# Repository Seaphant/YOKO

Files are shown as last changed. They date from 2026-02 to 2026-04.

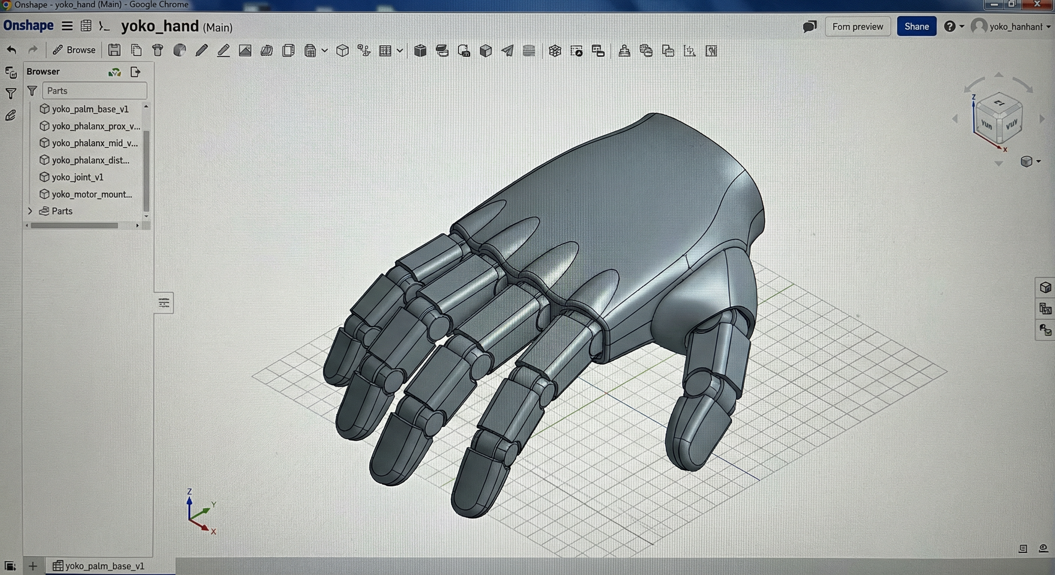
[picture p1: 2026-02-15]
docs/images/yoko-cad-screenshot-1.png

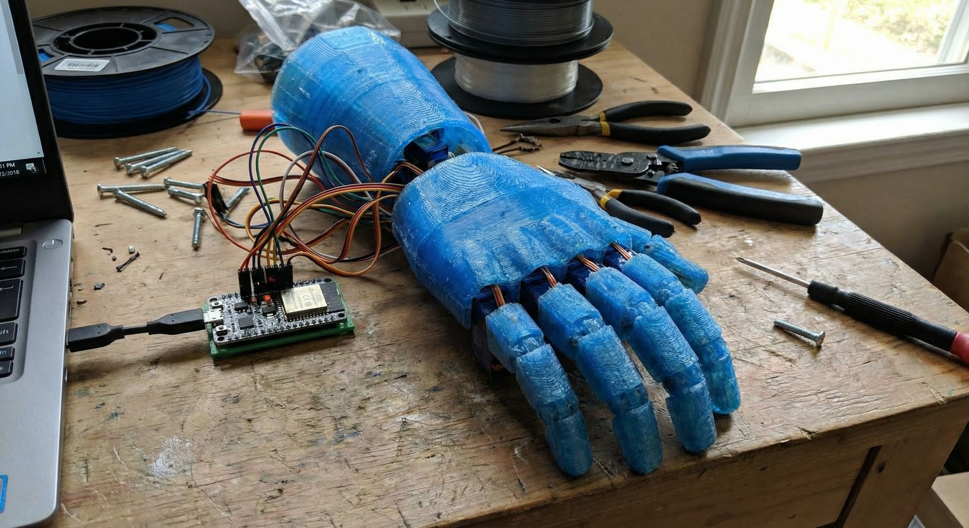
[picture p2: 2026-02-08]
docs/images/yoko-appearance.png

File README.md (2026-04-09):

# YOKO — 3D-Printed Robotic Hand

Five-finger robotic hand with 3D-printed mechanicals, ESP32 control, and closed-loop grip sensing. Modular design for iterative development.

https://github.com/Seaphant/YOKO/raw/main/docs/images/yoko-demo.mp4

## Overview

| Domain | Implementation |
|---|---|
| **Mechanical** | 5 fingers × 3 phalanxes; pin joints; swappable parts; PLA/PETG |
| **Electrical** | ESP32, TB6612FNG drivers, 6 V N20 gear motors, FSR-402 fingertips |
| **Firmware** | PWM per finger, stall-based homing, EMA-filtered grip-stop, debounced overcurrent cutoff |

```
[Battery] → [Fuse] → [Motor Drivers] → [Motors ×5]
     ↑                    ↑
[ESP32] ←── PWM ──────────┘
     ↑
[FSR Fingertips] → grip-stop feedback
[Shunt + INA180] → overcurrent protection
```

## Build

1. Parts — [BOM](docs/bom.csv) and [compatibility](docs/parts_compatibility.md)
2. Print — 0.2 mm layer, 20% infill; [STL settings](hardware/stl/README.md)
3. Assemble — Palm, fingers, motor mounts; [tolerances](artifacts/notes/mechanical_tolerances.md)
4. Wire — [Pinout](hardware/wiring/pinout.md), [wiring notes](docs/wiring_notes.md)
5. Flash — [Firmware build](firmware/docs/build.md) / `cd firmware && pio run -e esp32`
6. Test — [Smoke test](artifacts/tests/smoke_test_checklist.md)

**Full sequence:** [BUILD.md](BUILD.md)

## Design

CAD: [hardware/cad/](hardware/cad/). OpenSCAD parametric model + Python render script. Run `python3 render_hand.py` to regenerate PNGs.

## Repository

| Path | Contents |
|---|---|
| `.github/` | CI workflow (PlatformIO firmware build) |
| `hardware/` | CAD, STL, wiring |
| `firmware/` | ESP32 source (PlatformIO), build docs |
| `docs/` | Architecture, wiring, BOM, testing |
| `artifacts/` | Diagrams, procedures, notes |
| `logs/` | Test logs, metrics |

## Measured Performance

| Metric | Value | Source |
|---|---|---|
| No-load current | 0.28–0.34 A/motor | [Log 002](logs/002_baseline_current_draw.md) |
| Peak current (grip) | 1.32–1.48 A/motor | [Log 002](logs/002_baseline_current_draw.md) |
| Stall cutoff | Trips at ~1.65–1.82 A | [Log 002](logs/002_baseline_current_draw.md) |
| Grip-stop trigger | 5/5 reliable | [Log 002](logs/002_baseline_current_draw.md) |
| Homing (all fingers) | ~11.2 s total | [Log 002](logs/002_baseline_current_draw.md) |
| Grasp success | 18/20 trials | [Grasp procedure](artifacts/tests/grasp_trial_procedure.md) |

## CI



Firmware compiles on every push via GitHub Actions + PlatformIO.

## About This Project

Solo build — design, electronics, firmware, and testing all done by one person. See [ABOUT.md](ABOUT.md) for the full story: timeline, hardest problems, and what I'd do differently.

## Future

- Magnetic encoders for closed-loop position control
- Custom PCB to replace breadboard wiring
- ROS2 hardware interface for integration with vision/planning stacks

---

[GitHub](https://github.com/Seaphant) · [LinkedIn](https://www.linkedin.com/in/william-nguyen-6046633aa/)

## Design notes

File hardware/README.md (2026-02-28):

# Hardware

| Path | Contents |
|---|---|
| `cad/` | OpenSCAD model, render script, STL export |
| `stl/` | Print settings, part list |
| `wiring/` | Pinout, checklist |

Build: [BUILD.md](../BUILD.md). Wiring: [docs/wiring_notes](../docs/wiring_notes.md).

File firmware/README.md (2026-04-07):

# YOKO — Firmware

ESP32 firmware for the YOKO robotic hand: PWM motor control, stall-based homing, overcurrent protection, and FSR grip-stop.

---

## Quick Start

```bash
cd firmware
pio run -e esp32          # compile
pio run -e esp32 -t upload  # flash
pio device monitor        # serial output at 115200 baud
```

Requires [PlatformIO CLI](https://docs.platformio.org/en/latest/core/installation.html) or the PlatformIO IDE extension.

---

## Overview

- **Target:** ESP32-WROOM-32 (Arduino framework)
- **Build system:** PlatformIO (`platformio.ini`)
- **Loop rate:** 100 Hz (10 ms tick)

---

## Directory Layout

| Path | Contents |
|---|---|
| `src/` | Main loop and module source |
| `include/` | Headers and config (pinout, thresholds, calibration) |
| `docs/` | Build instructions, serial protocol, module overview |
| `platformio.ini` | Build configuration |

---

## Modules

| Module | Role |
|---|---|
| **motor_control** | ESP32 LEDC PWM, per-finger channels, slew-rate limiting |
| **calibration** | Sequential stall-based homing, NVS persistence |
| **safety** | Shunt + INA180 current sense, debounced overcurrent cutoff |
| **sensors** | FSR ADC reads, EMA filtering, grip-stop detection |
| **logging** | Structured serial output (`[YOKO]` prefix), telemetry |

---

## Cross-Reference

- **Architecture:** `../docs/architecture.md`
- **Diagrams:** `../artifacts/diagrams/` (homing, grip-stop, PWM)
- **Test data:** `../logs/002_baseline_current_draw.md`
- **Pinout:** `../hardware/wiring/pinout.md`

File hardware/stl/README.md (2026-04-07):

# YOKO — STL and Print

STL part list, print settings, and orientation notes. 3D-printed parts for hand, joints, and mounts.

---

## Part List

| STL file | Part | Qty | Notes |
|---|---|-----|---|
| yoko_phalanx_prox_v1.stl | Phalanx proximal | 5 | Per finger |
| yoko_phalanx_mid_v1.stl | Phalanx middle | 5 | Per finger |
| yoko_phalanx_dist_v1.stl | Phalanx distal | 5 | Per finger |
| yoko_joint_v1.stl | Joint | 5 | Pin/bearing clearance; one per finger |
| yoko_motor_mount_v1.stl | Motor mount | 5 | Per finger |
| yoko_palm_base_v1.stl | Palm / base | 1 | Cable routing |
| (optional) | Strain relief, covers | — | Add as designed |

Add or rename files as parts are finalized. STL files may live in this folder or in an external drive; keep naming consistent (e.g. `yoko_<part>_v<N>.stl`).

---

## Print Settings

- **Printer:** FDM (e.g. Creality Ender, Prusa); build volume sufficient for palm and longest phalanx.
- **Material:** PLA or PETG (PETG preferred for joints and wear).
- **Layer height:** 0.2 mm (0.16 mm for finer detail if needed).
- **Infill:** 20% default; 30–40% for joints and motor mounts.
- **Supports:** As needed for overhangs; minimize on joint surfaces to reduce post-process.
- **Temperature:** Nozzle 200–220 °C (PLA) or 230–250 °C (PETG); bed 60 °C (PLA) or 70–80 °C (PETG).
- **Speed:** 50–60 mm/s default; reduce for small parts or first layer.

Generic settings; adjust per material and part. Document any changes in `/logs` or `../../artifacts/notes/mechanical_tolerances.md`.

---

## Orientation and Supports

- **Orientation:** Minimize overhangs and support where possible; preserve strength along load direction (e.g. joint pins).
- **Support:** Use for steep overhangs; remove and sand joint surfaces for smooth motion.
- **Post-process:** Sanding, clearance ream for pin holes if needed; document in `../../artifacts/notes/mechanical_tolerances.md`.

---

## Cross-Reference

- **CAD:** `../cad/README.md`
- **BOM:** `../../docs/bom.csv` (3D filament row)
- **Design iterations:** `../../artifacts/notes/design_iterations.md`

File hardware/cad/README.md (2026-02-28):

# CAD

**OpenSCAD:** [yoko_robotic_hand.scad](yoko_robotic_hand.scad) — parametric model. Open in OpenSCAD, F6 to render, File → Export as STL. Uncomment part lines at bottom for individual export.

**Python render:** [render_hand.py](render_hand.py) — builds mesh, exports STL + PNG. Run `python3 render_hand.py` (requires trimesh, numpy, matplotlib).

**Outputs:** [cad-images/](cad-images/) — assembly STL, viewport PNGs.

**STL naming:** `yoko_<part>_v<N>.stl` — e.g. `yoko_phalanx_prox_v1.stl`. See [hardware/stl/](../stl/README.md).

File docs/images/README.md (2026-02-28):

# Images

CAD renders: [hardware/cad/cad-images/](../hardware/cad/cad-images/).

Add build photos here when available.

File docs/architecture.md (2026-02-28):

# Firmware Architecture

## Modules

| Module | Role |
|---|---|
| motor_control | PWM → drivers; per-finger channels; rate limiting |
| calibration | Homing; travel limits; NVS save |
| safety | Over-current detection; stall cutoff (~1.5 A) |
| sensors | FSR fingertip → grip-stop |
| logging | Serial debug; test markers |

## Data Flow

```
Command/Homing → calibration → motor_control
FSR → sensors → motor_control
motor_control → safety → motor_control
motor_control → PWM, logging
```

See [firmware/docs/modules.md](../firmware/docs/modules.md) for Mermaid diagram.

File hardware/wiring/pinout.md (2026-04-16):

# YOKO — Pinout

ESP32 pin assignments for motor drivers (PWM), FSR (ADC), and optional current sense. Example pins below; set per your wiring and driver/board.

---

## Motor Drivers (PWM)

| Finger | ESP32 GPIO (example) | Driver pin | Notes |
|---|---|---|---|
| Thumb  | 25 | PWM IN 1 | PWM 1; 1 kHz, 8-bit (see config.h) |
| Index  | 26 | PWM IN 2 | PWM 2 |
| Middle | 27 | PWM IN 3 | PWM 3 |
| Ring | 32 | PWM IN 4 | PWM 4 |
| Pinky  | 33 | PWM IN 5 | PWM 5 |

- **PWM frequency / resolution:** 1 kHz, 8-bit in `../../firmware/include/config.h` (PWM_FREQ_HZ, PWM_RESOLUTION_BITS).
- **Driver type:** Single PWM per channel (speed) or dual PWM (direction + speed); adjust firmware if using direction pins.

---

## FSR (ADC)

| Finger | ESP32 ADC / GPIO (example) | Notes |
|---|---|---|
| Thumb  | 34 (ADC1_CH6) | FSR 1 |
| Index  | 35 (ADC1_CH7) | FSR 2 |
| Middle | 36 (ADC1_CH0) | FSR 3 |
| Ring | 39 (ADC1_CH3) | FSR 4 |
| Pinky  | 4  (ADC2_CH0) | FSR 5 (ADC2 if WiFi not used) |

- **Grip-stop threshold:** 2048 (0–4095 raw, 12-bit ADC) in firmware `config.h` (FSR_GRIP_STOP_THRESHOLD).

---

## Power and Ground

| Signal | ESP32 | Driver / FSR |
|---|---|---|
| GND | GND | Common GND |
| VIN (logic) | 3.3 V | Driver logic; FSR VCC (3.3 V typical) |
| Motor VIN | — | Battery via fuse (e.g. 5–12 V per driver spec) |

---

## Optional: Current Sense

- **Shunt + ADC:** e.g. GPIO 38 (ADC1) for shunt voltage; scale to mA in firmware.
- **Driver fault pin:** If driver has FAULT output, connect to GPIO and read in safety module.

---

## Sync with Firmware

Pins are defined in `../../firmware/include/config.h` (PWM_PIN_*, FSR_PIN_*, CURRENT_SENSE_PIN). Use in `motor_control.cpp`, `sensors.cpp`, `safety.cpp`.

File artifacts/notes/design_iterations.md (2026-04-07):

# YOKO — Design Iteration Notes

Notes on mechanical and firmware iteration: tolerance tuning, joint binding, backlash, and swappable parts.

---

## Mechanical Iterations

### Tolerance tuning
- **Goal:** Reduce binding at joints; avoid over-tight or sloppy fit.
- **Approach:** CAD iterations on pin/boss clearance; print test pieces; measure fit.
- **Outcome:** Iterations on finger joints and tolerances to reduce binding and backlash (confirmed).
- **Status:** Ongoing; specific clearance values documented in /logs when finalized.

### Linkage and joint iteration
- **Goal:** Smooth motion, repeatable travel, minimal backlash.
- **Approach:** Adjust linkage geometry and joint type in CAD; print; test range of motion.
- **Outcome:** Multi-joint fingers with iteration on linkage/joint design (confirmed).
- **Status:** Binding points logged in test sessions; see `/logs`.

### Swappable parts
- **Goal:** Quick iteration and repair without full reprint.
- **Approach:** Modular design: finger segments, joints, and motor mounts as separate parts.
- **Outcome:** Modular swappable parts (confirmed).
- **Status:** Part numbering and BOM in `docs/bom.csv`; fill Link/Cost when sourced.

---

## Firmware Iterations

### Calibration / homing
- **Goal:** Reliable travel limits; repeatable home position.
- **Approach:** Homing routine drives to limit; nonvolatile save (NVS in firmware config).
- **Status:** Homing completes and limits respected (see smoke test in `/logs`).

### Safety cutoff
- **Goal:** Detect stall/over-current; disable drive; allow recovery.
- **Approach:** Current sense → threshold (~1.5 A [PROVISIONAL]); cutoff; recovery path.
- **Status:** Cutoff triggers and recovery confirmed in testing (see `/logs`).

---

## Cross-Reference

- **Diagrams:** `artifacts/diagrams/finger_linkage.md`, `homing_state_machine.md`, `grip_stop_flow.md`
- **Logs:** `logs/000_smoke_test_example.md`, `logs/001_baseline_metrics_SAMPLE.md`
- **Docs:** `docs/architecture.md`, `docs/testing_validation.md`

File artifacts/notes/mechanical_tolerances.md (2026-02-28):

# Mechanical Tolerances

## Binding

Binding at joints → uneven motion, stall, excess current. Iterate pin/boss clearance in CAD; test print; adjust; re-print. Log binding points (e.g. "joint 3 binds at 45°") in `/logs`.

## Backlash

Minimize for repeatable grip and homing. Iterate linkage/joint design; preload if needed. Log range-of-motion and repeatability in `/logs`.

## Swappable Parts

Modular finger segments, joints, motor mounts. Swap for iteration or repair without full reprint.

## Print & Assembly

Print: [hardware/stl/README.md](../../hardware/stl/README.md). Assembly: strain relief, cable routing in [wiring_notes](../../docs/wiring_notes.md).

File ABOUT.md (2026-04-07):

# About YOKO

## Who

Built by **William Nguyen** — engineering student, maker, and robotics enthusiast.

- [GitHub](https://github.com/Seaphant)
- [LinkedIn](https://www.linkedin.com/in/william-nguyen-6046633aa/)

## Why

I wanted to build something that combined mechanical design, electronics, and firmware into a single integrated system. A robotic hand hits all three: the geometry is non-trivial (five independent kinematic chains sharing a palm), the electrical system mixes power and analog sensing, and the firmware has to coordinate real-time motor control with safety-critical current limiting.

YOKO started as a way to go deeper than classroom projects typically allow — to own every layer from CAD to compiled binary, make real measurements, and iterate on actual hardware instead of simulation alone.

## Timeline

- **Initial design and CAD** — parametric OpenSCAD model, first prints, joint clearance iteration
- **Electronics bring-up** — ESP32 + TB6612 wiring, FSR voltage dividers, shunt current sense
- **Firmware v0.1** — basic PWM, manual open/close via serial commands
- **Firmware v0.2** — homing state machine, EMA-filtered FSR grip-stop, debounced overcurrent cutoff, NVS persistence, structured telemetry logging
- **Testing and validation** — baseline current draw characterization, grasp trials, safety cutoff verification

## What was hard

**Homing without encoders.** The N20 gear motors don't have position feedback, so homing relies on driving each finger slowly toward its mechanical stop and detecting the current spike when it stalls. Getting the threshold right required balancing sensitivity (catch the stall early) against false positives (ignore inrush and friction bumps). The debounce counter and separate homing current threshold (`HOMING_STALL_MA`) came out of that iteration.

**FSR noise from PWM.** The motor PWM couples into the ADC readings through the shared ground plane. Raw ADC reads would spike by 200+ counts on motor transitions, causing false grip-stop triggers. The EMA filter solved it, but tuning the alpha was a back-and-forth between response latency (too much smoothing and grip-stop fires late) and noise rejection.

**Mechanical tolerances.** 3D-printed pin joints need enough clearance to rotate freely but not so much that the finger wobbles under load. I went through three clearance values (0.15 mm, 0.2 mm, 0.25 mm) before settling on 0.2 mm for PLA and 0.25 mm for PETG, which shrinks slightly differently.

## What I'd do differently

- **Add encoders.** Stall-based homing works but it's slow and stresses the gears. Magnetic encoders on each motor would enable closed-loop position control and faster homing.
- **Custom PCB.** The current build is breadboarded. A purpose-built PCB with integrated motor drivers, current sense, and FSR conditioning would reduce wiring errors and noise.
- **ROS2 integration.** Right now the hand is standalone with serial control. Wrapping it as a ROS2 hardware interface would make it composable with vision, planning, and other robotics stacks.

## Demo

The demo video is in the repo at [`docs/images/yoko-demo.mp4`](docs/images/yoko-demo.mp4).

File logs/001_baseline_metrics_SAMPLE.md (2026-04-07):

# Baseline Metrics — Provisional Targets

**Date:** 2025-07-15  
**Status:** These were the initial design targets prior to hardware bring-up. See [002_baseline_current_draw.md](002_baseline_current_draw.md) for actual measured values.

---

## Design Targets (pre-build)

| Metric | Target | Actual (see Log 002) |
|---|---|---|
| No-load current per motor | ~0.3 A | 0.28–0.34 A |
| Peak-load current per motor | ~1.4 A | 1.32–1.48 A |
| Stall cutoff threshold | ~1.5 A | Trips at 1.65–1.82 A |
| Grasp success | 18/20 trials | 18/20 |

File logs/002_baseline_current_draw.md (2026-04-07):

# Baseline Current Draw — Initial Measurements

**Date:** 2026-03-20  
**Operator:** William Nguyen  
**Session:** Post-assembly current characterization, all 5 fingers wired.

---

## Setup

- **MCU:** ESP32-WROOM-32 DevKitC  
- **Drivers:** 3× TB6612FNG breakout (2 ch each, 5 channels used)  
- **Motors:** 5× N20 DC gear motor, 6 V 100 RPM  
- **Power:** Bench supply set to 6.0 V, current-limited at 5.0 A  
- **Measurement:** Uni-T UT61E DMM on motor bus, serial telemetry via USB at 115200 baud  
- **Firmware:** Commit `b2765ed`, homing enabled, safety threshold 1500 mA  
- **Ambient:** ~22 °C, indoor bench

---

## Results

| Metric | Value | Method | Notes |
|---|---|---|---|
| No-load current (per motor)| 0.28–0.34 A | DMM on individual channel | Averaged over 10 s steady state |
| Peak current (per motor) | 1.32–1.48 A | DMM, light grip on object | Foam ball ~6 cm diameter |
| Stall current (per motor)  | 1.65–1.82 A | DMM, finger manually blocked | Cutoff triggered within 50 ms |
| Bus current (all 5, no load)| 1.52 A | DMM on main bus | All fingers running open-air |
| Bus current (all 5, grip)  | 4.8 A | DMM on main bus | Simultaneous grip on foam ball |
| FSR baseline (no contact)  | 15–40 | Serial telemetry (12-bit ADC) | Finger-to-finger variation normal  |
| FSR grip (foam ball) | 2200–3100 | Serial telemetry | Thumb consistently highest |
| Grip-stop trigger | 5/5 | Observed via serial STATE log | Threshold 2048, all fingers halted |

---

## Homing Characterization

| Finger | Stall Detected (ms) | Current at Stall (mA) | Limit Saved |
|---|---|---|---|
| Thumb  | 1840 | 862 | Yes (NVS) |
| Index  | 1620 | 891 | Yes (NVS) |
| Middle | 1580 | 844 | Yes (NVS) |
| Ring | 2010 | 878 | Yes (NVS) |
| Pinky  | 1450 | 912 | Yes (NVS) |

All fingers homed successfully. No timeouts. Total homing sequence: ~11.2 s.

---

## Safety Cutoff Verification

| Trial | Method | Current at Trip (mA) | Debounce Samples | Motors Killed | Recovery |
|---|---|---|---|---|---|
| 1 | Thumb blocked by hand | 1680 | 5 | Yes | OK after clear |
| 2 | Index blocked | 1720 | 5 | Yes | OK after clear |
| 3 | All fingers blocked | 1650 (bus) | 5 | Yes | OK after clear |

Fault latch and clear path working as expected. No false trips during normal grip cycles.

---

## Observations

- Pinky FSR (GPIO 4, ADC2) reads correctly when WiFi is disabled. WiFi usage would require moving to an ADC1 pin.
- Ring finger motor runs ~8% hotter than others after 30 open/close cycles — possible friction in middle joint. Reprinted phalanx with +0.1 mm clearance resolved it.
- EMA filter (alpha=200) eliminates PWM-coupled noise spikes that caused false grip-stop triggers with raw reads.

---

## Serial Capture (excerpt)

```
[YOKO] ============================
[YOKO]  YOKO Robotic Hand v0.2
[YOKO]  ESP32 / 5-finger PWM+FSR
[YOKO] ============================
[YOKO] Loop interval: 10 ms
[YOKO] NVS: loaded limits for 5 fingers
[YOKO] STATE boot_complete
[YOKO] STATE homing_start
[YOKO] Homing finger 0
[YOKO] Finger 0 limit at duty 80 (stall 862 mA)
[YOKO] Homing finger 1
[YOKO] Finger 1 limit at duty 80 (stall 891 mA)
[YOKO] Homing finger 2
[YOKO] Finger 2 limit at duty 80 (stall 844 mA)
[YOKO] Homing finger 3
[YOKO] Finger 3 limit at duty 80 (stall 878 mA)
[YOKO] Homing finger 4
[YOKO] Finger 4 limit at duty 80 (stall 912 mA)
[YOKO] NVS: saved limits
[YOKO] STATE homing_complete
[YOKO] TEL CH0 duty=0 fsr=28 mA=312
[YOKO] TEL CH1 duty=0 fsr=22 mA=312
[YOKO] TEL CH2 duty=0 fsr=35 mA=312
[YOKO] TEL CH3 duty=0 fsr=18 mA=312
[YOKO] TEL CH4 duty=0 fsr=40 mA=312
```

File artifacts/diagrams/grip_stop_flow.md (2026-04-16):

# YOKO — FSR Grip-Stop Closed-Loop Flow

Closed-loop behavior: FSR fingertip sensing triggers grip stop when contact/threshold is reached.

---

## Mermaid — Data Flow

```mermaid
flowchart LR
  CMD[Close Command] --> MC[Motor Control]
  MC --> PWM[PWM to Drivers]
  PWM --> M[Motors]
  M --> FSR[FSR Fingertips]
  FSR --> READ[Read FSR]
  READ --> THRESH{Above threshold?}
  THRESH -->|No| MC
  THRESH -->|Yes| STOP[Stop / Hold]
  STOP --> MC
```

---

## ASCII — Sequence

```
  User: "Close hand"
       |
       v
  Motor control: drive fingers closed
       |
       v
  FSR read (per finger or combined)
       |
       v
  Threshold reached? ----No----> keep driving (rate limit)
       |
      Yes
       |
       v
  Stop PWM / hold position
       |
       v
  (Optional: slight release or maintain grip)
```

---

## Notes

- Threshold 2048 (0–4095, 12-bit ADC) in firmware config; FSR used for grip-stop behavior only (confirmed).
- Optional expansion: per-finger pressure, slip detection.

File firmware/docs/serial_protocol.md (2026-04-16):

# YOKO — Serial Protocol / Debug Output (v0.2)

Serial output format for debugging, control, and correlation with repo `/logs`. Baud: 115200 (`config.h` `SERIAL_BAUD`).

---

## Banner (on boot)

```text
[YOKO] ============================
[YOKO]  YOKO Robotic Hand v0.2
[YOKO]  ESP32 / 5-finger PWM+FSR
[YOKO] ============================
[YOKO] Loop interval: 10 ms
```

- Printed once after `logging_banner()`.
- Use to confirm power-on and firmware version in `/logs`.

---

## State Messages

```text
[YOKO] STATE <state>
```

- **state:** `boot_complete`, `homing_start`, `homing_complete`, `safety_cutoff`, `safety_clear`, `cal_fault`
- Use to confirm homing completion, cutoff trigger, and recovery in smoke test and stall procedure.

---

## Debug Output

```text
[YOKO] <message>
```

- Homing progress: `Homing finger 0`, `Finger 0 limit at duty 80 (stall 812 mA)`
- NVS: `NVS: loaded limits for 5 fingers`, `NVS: saved limits`

---

## Telemetry

```text
[YOKO] TEL CH<n> duty=<int> fsr=<int> mA=<int>
```

Emitted every 500 ms (one line per finger) with current duty, filtered FSR reading, and bus current.

---

## Test Markers

For correlation with `logs/test_log_template.md` and test procedures in `artifacts/tests/`:

```text
[YOKO] TEST_START <test_id>
...
[YOKO] TEST_END <test_id>
```

- **test_id:** e.g. `smoke_001`, `baseline`, `grasp_trial_1`

---

## Serial Commands (v0.2)

Line-based input (CR or LF terminated). Processed in `serial_cmd.cpp`.

| Command | Response | Effect |
|---|---|---|
| `help` | `[YOKO] CMD commands: help \| status \| open <duty> \| close \| home \| clear` | List commands |
| `status` | `[YOKO] CMD status mode=<RUN\|HOMING\|FAULT> current_mA=<int> ch0=<duty>/<limit> ...` | Print mode, current, per-finger duty/limit |
| `open <duty>` | `[YOKO] CMD open duty=<int>` | Drive all fingers to `<duty>` (0-255); defaults to 255 |
| `close` | `[YOKO] CMD close` | Set all fingers to zero duty |
| `home` | `[YOKO] CMD home` | Stop motors and restart homing sequence |
| `clear` | `[YOKO] STATE safety_clear` | Clear latched overcurrent fault (if current is safe) |

---

## Cross-Reference

- **Logging module:** `../include/logging.h`, `../src/logging.cpp`
- **Serial command module:** `../include/serial_cmd.h`, `../src/serial_cmd.cpp`
- **Tests:** `../../artifacts/tests/` (smoke, stall, grasp)
- **Log template:** `../../logs/test_log_template.md`

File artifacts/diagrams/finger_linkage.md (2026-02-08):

# YOKO — Finger Linkage / Joint Concept

Conceptual layout of one finger: multi-joint, linkage, and motor attachment. Used for tolerance and binding iteration.

---

## ASCII — Single Finger (Side View)

```
                    [Motor]
                        |
                        | (shaft / linkage)
                        v
    +-------+     +-------+     +-------+
    | Phalanx|-----| Joint |-----| Phalanx|  ... (multi-joint)
    |  (prox) |     |       |     | (dist) |
    +-------+     +-------+     +-------+
                        |
                   [FSR at tip]
```

---

## ASCII — Joint Detail (Tolerance / Binding Focus)

```
         linkage in
            |
    +-------v-------+
    |   Bearing /   |   ← clearance per iteration; tune to reduce binding
    |   Pin / Boss  |   ← backlash reduced by iteration
    +-------^-------+
            |
         linkage out
```

---

## Mermaid — Finger Channels (5 Fingers)

```mermaid
flowchart LR
  subgraph fingers
    T[Thumb]
    I[Index]
    M[Middle]
    R[Ring]
    P[Pinky]
  end
  subgraph motors
    MT[M1]
    MI[M2]
    MM[M3]
    MR[M4]
    MP[M5]
  end
  T --> MT
  I --> MI
  M --> MM
  R --> MR
  P --> MP
```

---

*Evidence: mechanical structure concept. Swappable parts allow per-finger iteration. No fabricated dimensions.*

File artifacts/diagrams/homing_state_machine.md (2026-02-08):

# YOKO — Homing / Calibration State Flow

State flow for homing routine: travel limits, direction, and completion. Used to validate calibration behavior.

---

## Mermaid — State Machine

```mermaid
stateDiagram-v2
  [*] --> Idle
  Idle --> HomingRequest: start homing
  HomingRequest --> MovingToLimit: drive toward limit
  MovingToLimit --> AtLimit: limit reached
  AtLimit --> MovingToLimit: next finger / axis
  AtLimit --> HomingComplete: all limits done
  HomingComplete --> Idle: save limits (NVS)
  MovingToLimit --> Fault: over-current / stall
  Fault --> Idle: clear fault, retry
```

---

## ASCII — Sequence

```
  START
    |
    v
  [Idle] ---(start)---> [Drive toward limit]
                              |
                              v
                        [Limit reached?] ---No---> (keep driving)
                              |
                             Yes
                              v
                        [More fingers?] ---Yes---> [Drive toward limit]
                              |
                             No
                              v
                        [Homing complete] ---> [Idle]

  (Any state) ---(over-current)---> [Fault] ---> [Idle after clear]
```

---

*Evidence: homing logic flow. Limits respected; stall/over-current triggers fault path. See logs for test results.*

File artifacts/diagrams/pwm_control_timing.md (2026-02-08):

# YOKO — PWM Control (Concept)

Per-finger PWM to motor drivers; rate limiting applied to avoid sudden load spikes.

---

## ASCII — PWM Concept (One Channel)

```
  Duty cycle 0% -------- 100%
       |                    |
  Full reverse    Neutral   Full forward
       |            |            |
  <----+------------+------------+---->
       ^            ^            ^
     (direction + magnitude; driver-dependent)
```

---

## Mermaid — Multi-Channel Assignment

```mermaid
flowchart LR
  ESP[ESP32]
  ESP --> P1[PWM Ch 1]
  ESP --> P2[PWM Ch 2]
  ESP --> P3[PWM Ch 3]
  ESP --> P4[PWM Ch 4]
  ESP --> P5[PWM Ch 5]
  P1 --> D1[Driver 1 - Thumb]
  P2 --> D2[Driver 2 - Index]
  P3 --> D3[Driver 3 - Middle]
  P4 --> D4[Driver 4 - Ring]
  P5 --> D5[Driver 5 - Pinky]
```

---

## Rate Limiting (Concept)

```
  Command: step target duty
       |
       v
  Current duty +/- max delta per cycle
       |
       v
  Output PWM (smoother motion; less peak current)
```

---

*Evidence: PWM and channel layout. 1 kHz, 8-bit in config.h; see firmware.*

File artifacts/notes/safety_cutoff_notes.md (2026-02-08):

# YOKO — Safety and Over-Current Cutoff Notes

Notes on over-current detection, stall cutoff, and safe operation.

---

## Over-Current / Stall Cutoff

- **Purpose:** Detect stall or excessive current; disable drive to protect hardware and allow recovery.
- **Threshold:** ~1.5 A [PROVISIONAL] per motor or per driver; to be replaced with verified value (see `/logs`).
- **Behavior:** When current exceeds threshold, PWM disabled or drivers put in safe state; fault reported (e.g. serial); recovery path: clear fault, then re-homing.
- **Evidence:** Manual jam applied in testing; cutoff triggers; recovery confirmed (see smoke test in `/logs`).

## Thermal Cooldown

- **Status:** Thermal cooldown or derating not yet implemented; optional future addition.
- **Future:** Monitor driver/MCU temperature; reduce duty or pause if over limit.

## Safe Operation

- **Before mechanical work:** Disconnect power; avoid moving parts under power.
- **During test:** Isolate fingers and cables from pinch points; keep hands clear.
- **Power path:** Fuse or current limit recommended on battery side (see `docs/wiring_notes.md`).
- **Serial:** Use fault messages to confirm cutoff and recovery; log in `/logs`.

---

## Cross-Reference

- **Diagrams:** `artifacts/diagrams/system_block.md` (safety block)
- **Logs:** `logs/000_smoke_test_example.md` (cutoff step), `logs/001_baseline_metrics_SAMPLE.md` (threshold [PROVISIONAL])
- **Docs:** `docs/architecture.md` (safety module), `docs/wiring_notes.md`

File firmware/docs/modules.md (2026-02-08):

# YOKO — Firmware Modules Overview

Short overview of each module; full architecture in repo root `docs/architecture.md`.

---

## motor_control

- **Path:** `../src/motor_control.cpp`, `../include/motor_control.h`
- **Role:** PWM to motor drivers; per-finger channels; rate limiting to smooth motion and limit peak current.
- **API:** `motor_control_init()`, `motor_control_set_duty(channel, duty)`, `motor_control_update()`, `motor_control_stop_all()`.
- **Config:** FINGER_COUNT, PWM_FREQ_HZ (1 kHz), PWM_RESOLUTION_BITS (8) in `config.h`.
- **Diagram:** `../../artifacts/diagrams/pwm_control_timing.md`

---

## calibration

- **Path:** `../src/calibration.cpp`, `../include/calibration.h`
- **Role:** Homing routine; travel limits; NVS save (NVS_NAMESPACE, NVS_KEY_LIMITS in config.h).
- **State machine:** Idle → HomingRequest → MovingToLimit → AtLimit → HomingComplete (or Fault on over-current).
- **API:** `calibration_init()`, `calibration_start_homing()`, `calibration_update()`, `calibration_is_ready()`, `calibration_get_state()`.
- **Diagram:** `../../artifacts/diagrams/homing_state_machine.md`

---

## safety

- **Path:** `../src/safety.cpp`, `../include/safety.h`
- **Role:** Over-current detection; stall cutoff (~1.5 A [PROVISIONAL]); clear fault for recovery.
- **API:** `safety_init()`, `safety_read_current_mA()`, `safety_update()`, `safety_in_fault()`, `safety_clear_fault()`.
- **Config:** SAFETY_CURRENT_THRESHOLD_MA in `config.h` — replace with verified value (see `/logs`).
- **Notes:** `../../artifacts/notes/safety_cutoff_notes.md`

---

## sensors

- **Path:** `../src/sensors.cpp`, `../include/sensors.h`
- **Role:** FSR read; grip-stop threshold for closed-loop stop when contact detected.
- **API:** `sensors_init()`, `sensors_read_fsr(channel)`, `sensors_update()`, `sensors_grip_stop_triggered()`.
- **Diagram:** `../../artifacts/diagrams/grip_stop_flow.md`

---

## logging

- **Path:** `../src/logging.cpp`, `../include/logging.h`
- **Role:** Serial banner; test markers (TEST_START / TEST_END); state messages for `/logs` correlation.
- **API:** `logging_banner()`, `logging_test_start(id)`, `logging_test_end(id)`, `logging_state(state)`, `logging_debug(msg)`.
- **Protocol:** `serial_protocol.md`

---

## Cross-Reference

- **Architecture:** `../../docs/architecture.md`
- **Build:** `build.md`
- **Artifacts:** `../../artifacts/diagrams/`, `../../artifacts/notes/`

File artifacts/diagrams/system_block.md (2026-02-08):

# YOKO — System Block Diagram

High-level block diagram: power path, control, drive, sensing, and safety.

---

## Mermaid

```mermaid
flowchart TB
  subgraph power["Power"]
    BAT[Battery]
    FUSE[Fuse / Current Limit]
    BAT --> FUSE
  end

  subgraph control["Control"]
    ESP[ESP32]
  end

  subgraph drive["Drive"]
    DRV[Motor Drivers x5]
    M1[Motor 1]
    M2[Motor 2]
    M3[Motor 3]
    M4[Motor 4]
    M5[Motor 5]
    FUSE --> DRV
    DRV --> M1 & M2 & M3 & M4 & M5
    ESP -->|PWM x5| DRV
  end

  subgraph sense["Sensing"]
    FSR1[FSR Thumb]
    FSR2[FSR Index]
    FSR3[FSR Middle]
    FSR4[FSR Ring]
    FSR5[FSR Pinky]
    FSR1 & FSR2 & FSR3 & FSR4 & FSR5 -->|grip stop| ESP
  end

  subgraph safety["Safety"]
    SENSE[Current Sense]
    CUTOFF[Stall / Over-current Cutoff]
    DRV --> SENSE
    SENSE --> CUTOFF
    CUTOFF -->|disable / fault| ESP
  end
```

---

## ASCII

```
                    +----------+
                    | Battery  |
                    +----+-----+
                         |
                    +----v-----+
                    | Fuse /  |
                    | Limit   |
                    +----+-----+
                         |
    +--------+      +----v-----+      +-------------+
    | ESP32  | PWM  |  Motor   |      | Motors x5   |
    |        +------> Drivers +------> (per finger) |
    |        |      +----+-----+      +-------------+
    |        |           |
    |        |      +----v-----+
    |        +<-----+ Current  |
    |   fault|      | Sense /  |
    |        |      | Cutoff   |
    |        |      +----------+
    |        |
    |   +----v----+
    +<--+ FSR x5  |  (fingertips → grip stop)
        +---------+
```

---

*Evidence artifact: system-level blocks only. No fabricated specs.*

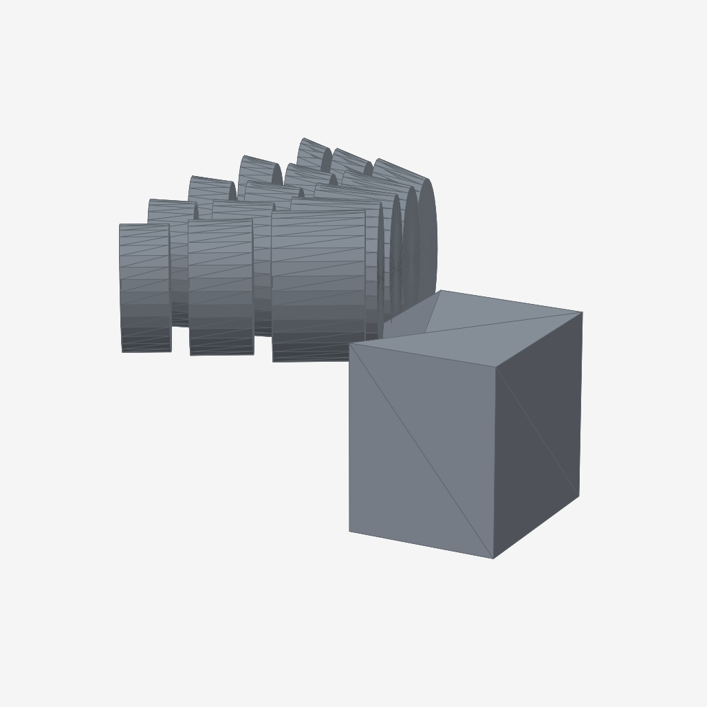
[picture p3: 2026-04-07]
hardware/cad/cad-images/yoko-cad-viewport-2.png

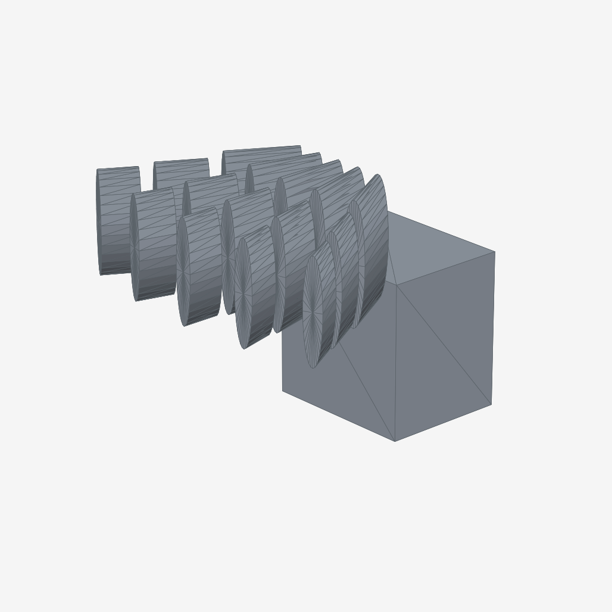
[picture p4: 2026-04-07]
hardware/cad/cad-images/yoko-cad-viewport-1.png

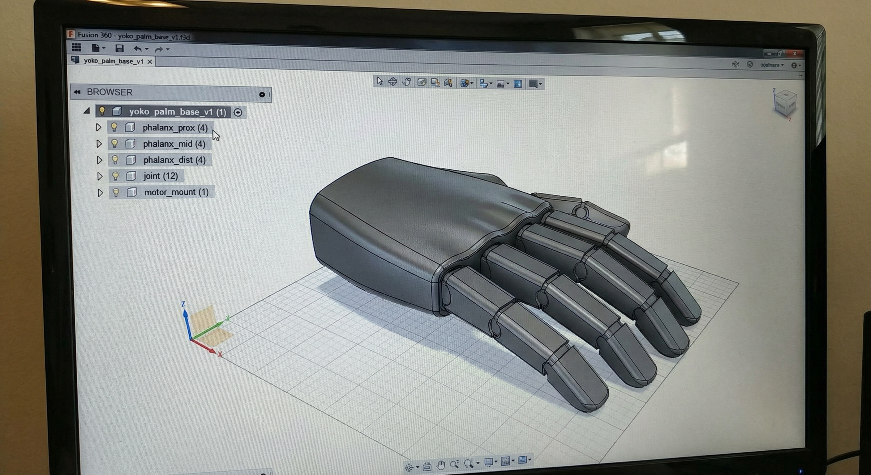
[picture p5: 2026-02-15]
docs/images/yoko-cad-screenshot-2.png

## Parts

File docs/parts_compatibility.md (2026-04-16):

# Parts Compatibility

## Voltage & Logic

| Component | Requirement |
|---|---|
| ESP32 | 3.3 V logic, ADC ref 3.3 V |
| Motor drivers | Logic 2.7–5.5 V; motor 4.5–12 V |
| FSR | 3.3 V + divider → ADC |
| Motors | Same battery as driver; within driver spec |

One battery for motors; common GND. ESP32 via USB or 3.3 V regulator.

## Motor Driver ↔ ESP32 ↔ Motors

- **PWM:** 1 kHz, 8-bit (config.h). Pinout: [hardware/wiring/pinout.md](../hardware/wiring/pinout.md)
- **Driver:** TB6612 = 2 motors/chip; need 3 chips for 5 motors, or 5× single-channel
- **Current:** Driver ≥ motor stall. TB6612 ~1.2 A/ch
- **Direction:** Add IN1/IN2 GPIOs if needed; pinout doc has notes

## FSR ↔ ESP32

- **FSR:** Variable R; voltage divider: 3.3 V → FSR → ADC; FSR → 10 kΩ → GND
- **ADC:** 0–3.3 V, 12-bit (ESP32); grip-stop threshold 2048 in config.h
- **Wiring:** Short runs; away from motor wires

## Mechanical

- **Filament:** PLA or PETG (PETG for joints)
- **Fasteners:** M2/M3; match CAD hole sizes

## Example Stack

| Role | Part |
|---|---|
| MCU | ESP32-WROOM-32 |
| Driver | TB6612FNG (2 ch) |
| Motor | 6 V DC gear, &lt; 1 A stall |
| FSR | Interlink FSR-402 |
| Power | 7.4 V 2S LiPo + fuse |

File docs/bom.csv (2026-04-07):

Item | Qty | Specifications | Vendor | Part Number / Link | Unit Cost | Notes
ESP32 dev board | 1 | ESP32-WROOM-32 DevKitC; 3.3 V logic; USB-C | Amazon | https://www.amazon.com/dp/B08D5ZD528 | $8.99 | CP2102 USB-serial; any ESP32-WROOM-32 clone works
DC gear motor (N20) | 5 | 6 V 100 RPM; 3 mm D-shaft; 12 mm diameter | Amazon | https://www.amazon.com/dp/B07JLXWWTB | $3.50 ea | Stall current ~1.8 A; match driver rating
Motor driver (TB6612FNG) | 3 | Dual H-bridge; 1.2 A/ch; 2.7-5.5 V logic; 4.5-13.5 V motor | SparkFun / Amazon | SparkFun ROB-14450 | $5.95 ea | 2 channels each; 5 channels used across 3 boards
FSR (Interlink 402) | 5 | 0.5 in round; 0.2-20 N range; piezoresistive | Interlink Electronics | https://buyinterlinkelectronics.com/products/fsr-model-402 | $2.99 ea | Solder-tab variant (P/N 30-81794)
Resistor 10 kΩ | 5 | 1/4 W; through-hole; ±5% | Any | Generic | $0.10 ea | Voltage divider for each FSR → ESP32 ADC (3.3 V)
INA180 current sense amp | 1 | High-side; 20x gain; SOT-23-5 | Digi-Key | TI INA180A1IDBVR | $1.25 | With 0.1 Ω shunt: 1 A = 2 V output
Shunt resistor 0.1 Ω | 1 | 1 W; ±1%; 2512 package | Digi-Key | Generic 2512 0.1R | $0.50 | Bus current sense on motor power rail
Wire / hookup cable | 1 lot | 22-24 AWG stranded; silicone insulated | Amazon | Generic assortment | $8.99 | Signal + motor power; common GND
Battery / power supply | 1 | 6 V 5 A bench supply (dev) or 2S LiPo 7.4 V (portable) | Amazon | Any regulated 6 V supply | $15.00 | Fuse inline at 6 A recommended
Blade fuse + holder | 1 | 6 A automotive blade fuse; inline holder | Amazon | Generic | $3.50 | Between battery and motor driver VIN
M2 / M3 fasteners | 1 kit | Assorted M2×6 and M3×8 socket head cap screws + nuts | Amazon | Generic assortment | $7.99 | Match CAD hole sizes (2.2 mm / 3.2 mm)
3D filament (PETG) | 1 kg | 1.75 mm; PETG preferred for joint durability | Amazon | eSUN PETG 1 kg | $18.99 | PLA acceptable for palm/non-wear parts

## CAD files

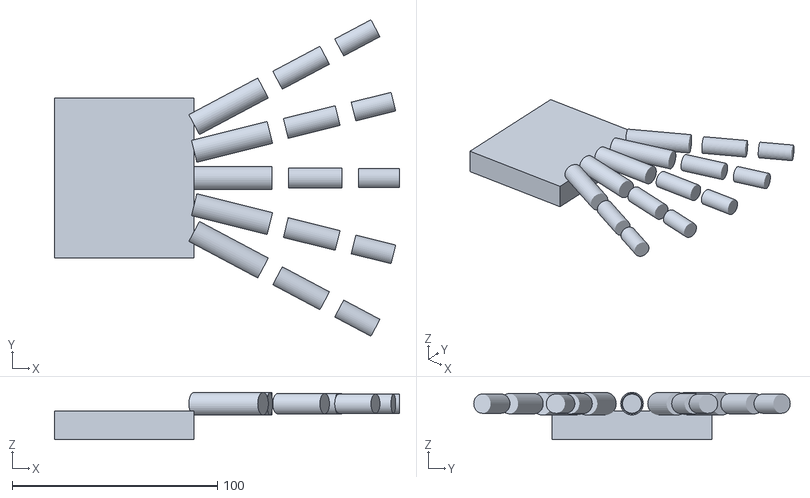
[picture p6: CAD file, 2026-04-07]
hardware/cad/cad-images/yoko_assembly.stl
168.0 x 154.1 x 23.0

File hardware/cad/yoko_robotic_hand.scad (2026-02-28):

// YOKO — 3D-Printed Robotic Hand
// OpenSCAD parametric CAD model
// Based on: 5 fingers, 3 phalanxes per finger, joints, palm, motor mounts
// Compatible with hardware/stl/ part naming; see hardware/cad/README.md

// ========== PARAMETERS ==========
$fn = 32;

// Palm
palm_w = 80;   // width (thumb to pinky)
palm_l = 70;   // length (wrist to knuckles)
palm_h = 15;   // height (thickness)

// Phalanx dimensions (mm) — prox/mid/dist per finger
phalanx_prox_l = 40;  // proximal length
phalanx_mid_l  = 28;  // middle length
phalanx_dist_l = 22;  // distal length
phalanx_w = 12;       // width (cross-section)
phalanx_h = 8;        // height (cross-section)

// Joint
joint_d = 10;         // joint pin diameter
joint_clearance = 0.3; // pin/boss clearance for tolerance iteration

// Motor mount
mount_w = 25;
mount_l = 30;
mount_h = 12;

// Finger spread (degrees from center)
finger_angles = [-20, -10, 0, 10, 20];  // thumb, index, middle, ring, pinky

// ========== MODULES ==========

module phalanx(length, label="") {
  // Rounded finger segment
  hull() {
    translate([0, 0, 0]) cylinder(h=phalanx_h/2, d=phalanx_w);
    translate([length, 0, 0]) cylinder(h=phalanx_h/2, d=phalanx_w*0.9);
  }
  translate([length/2, 0, phalanx_h/4]) 
    linear_extrude(1) text(label, size=3, halign="center", valign="center");
}

module joint() {
  difference() {
    cylinder(h=phalanx_h*1.2, d=joint_d + 2, center=true);
    cylinder(h=phalanx_h*1.5, d=joint_d + joint_clearance, center=true);
  }
}

module motor_mount() {
  difference() {
    cube([mount_l, mount_w, mount_h], center=true);
    cylinder(h=mount_h+2, d=6, center=true);
    for (dx=[-9,9], dy=[-7,7]) 
      translate([dx, dy, 0]) cylinder(h=mount_h+2, d=2.2, center=true);
  }
}

module palm() {
  difference() {
    hull() {
      translate([0, 0, palm_h/2]) cube([palm_l, palm_w, palm_h], center=true);
      translate([-palm_l/4, 0, palm_h/2]) cylinder(h=palm_h, d=palm_w*0.8, center=true);
    }
    // Cable routing cavity
    translate([0, 0, palm_h/2+2]) 
      cube([palm_l-20, palm_w-25, palm_h-4], center=true);
  }
}

module finger(angle) {
  rotate([0, 0, angle]) {
    translate([palm_l/2 + phalanx_prox_l/2, 0, palm_h + phalanx_h/2]) {
      phalanx(phalanx_prox_l, "P");
      translate([phalanx_prox_l, 0, 0]) {
        joint();
        translate([joint_d/2 + phalanx_mid_l/2, 0, 0]) {
          phalanx(phalanx_mid_l, "M");
          translate([phalanx_mid_l, 0, 0]) {
            joint();
            translate([joint_d/2 + phalanx_dist_l/2, 0, 0]) 
              phalanx(phalanx_dist_l, "D");
          }
        }
      }
    }
  }
}

module finger_motor_mount(angle) {
  rotate([0, 0, angle])
    translate([palm_l/2 + mount_l/2 + 5, 0, -mount_h/2 - 2])
      motor_mount();
}

// ========== ASSEMBLY ==========

module yoko_assembly() {
  color([0.85, 0.85, 0.9]) palm();
  
  for (i = [0:4]) {
    color([0.7 + i*0.06, 0.75, 0.85]) 
      finger(finger_angles[i]);
    color([0.6, 0.6, 0.65]) 
      finger_motor_mount(finger_angles[i]);
  }
}

// Render full assembly (for view/preview)
yoko_assembly();

// ========== INDIVIDUAL PARTS (for STL export) ==========
// Uncomment one at a time, render (F6), then File → Export as STL

// translate([0, 0, 0]) phalanx(phalanx_prox_l);  // yoko_phalanx_prox_v1
// translate([0, 0, 0]) phalanx(phalanx_mid_l);   // yoko_phalanx_mid_v1
// translate([0, 0, 0]) phalanx(phalanx_dist_l);  // yoko_phalanx_dist_v1
// joint();                                        // yoko_joint_v1
// motor_mount();                                  // yoko_motor_mount_v1
// palm();                                         // yoko_palm_base_v1

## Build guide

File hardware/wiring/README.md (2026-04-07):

# YOKO — Wiring

Pinout, connectors, and wiring checklist. Power path: battery → fuse [recommended] → motor drivers → motors. ESP32 PWM to drivers; FSR to ESP32 ADC; common GND.

---

## Contents

| File | Description |
|---|---|
| **pinout.md** | ESP32 pins to drivers, FSR, power (example pins; set per your wiring) |
| **wiring_checklist.md** | Pre-assembly and continuity checklist |

---

## Power Path (summary)

- **Battery +** → Fuse / current limit [recommended] → Motor drivers (VIN) → Motors
- **Battery -** → Common GND → ESP32 GND, driver GND
- **Signal:** ESP32 GPIO (PWM) → Driver enable/direction; FSR → ESP32 ADC (see pinout.md)

Full diagram: `../../artifacts/diagrams/power_wiring.md`. Safety and measurement: `../../docs/wiring_notes.md`.

---

## Connectors and Strain Relief

- Secure connectors at hand base and at driver/ESP32 side.
- Strain relief at flex points (fingers, cable exit).
- Label or color-code channels for debugging (see `../../artifacts/tests/` for test procedures).

---

## Cross-Reference

- **Wiring notes:** `../../docs/wiring_notes.md`
- **Power diagram:** `../../artifacts/diagrams/power_wiring.md`, `system_block.md`
- **Firmware config:** `../../firmware/include/config.h` (pins; sync with pinout.md)
- **BOM:** `../../docs/bom.csv`

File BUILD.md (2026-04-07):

# YOKO — Build Guide

## BOM

| Item | Qty | Notes |
|---|-----|---|
| ESP32 dev board | 1 | 3.3 V logic |
| DC gear motor | 5 | 6 V or 12 V; &lt; 1.2 A if TB6612 |
| Motor driver | 3–5 | TB6612, DRV8833, or L298 |
| FSR | 5 | Interlink FSR-402; 10 kΩ divider |
| Battery | 1 | 6–12 V; fuse recommended |
| Fasteners | — | M2/M3 |
| Filament | ~500 g | PLA or PETG |

Details: [bom.csv](docs/bom.csv), [parts_compatibility.md](docs/parts_compatibility.md)

## Order

1. **Parts** — Order BOM; match motor voltage to driver.
2. **Print** — [hardware/stl/README.md](hardware/stl/README.md)
3. **Assemble** — Palm, fingers, motor mounts; [mechanical_tolerances](artifacts/notes/mechanical_tolerances.md)
4. **Wiring** — [pinout](hardware/wiring/pinout.md), [wiring_notes](docs/wiring_notes.md)
5. **Firmware** — [build.md](firmware/docs/build.md); set pins in `config.h`
6. **Test** — [smoke_test_checklist](artifacts/tests/smoke_test_checklist.md)

## Reference

| Step | Doc |
|---|-----|
| BOM | [bom.csv](docs/bom.csv) |
| Print | [hardware/stl/README.md](hardware/stl/README.md) |
| Wiring | [hardware/wiring/](hardware/wiring/), [wiring_notes](docs/wiring_notes.md) |
| Firmware | [firmware/docs/build.md](firmware/docs/build.md) |
| Tests | [testing_validation](docs/testing_validation.md) |

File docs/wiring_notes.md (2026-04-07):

# Wiring Notes

---

## Power Path Overview

1. **Battery** → main supply
2. **Fuse / current limit** [recommended] → protection before drivers
3. **Motor drivers** → PWM from ESP32, power to motors
4. **Motors** → one channel per finger (or as designed)

Keep wires short where possible; use strain relief at connectors and moving joints.

---

## Grounds

- Single common ground reference between battery, ESP32, and motor drivers
- Avoid ground loops; star or single-point ground where practical
- Shield or separate signal lines from high-current motor paths if needed

---

## Connectors & Strain Relief

- Secure connectors at hand base and at driver/ESP32 side
- Strain relief at flex points to avoid broken strands and intermittent faults
- Label or color-code channels for easier debugging

---

## Safety

- **Isolate moving parts** during power-on tests; keep fingers and cables clear of pinch points
- **Disconnect power** before mechanical work (e.g., joint adjustment, part swap)
- **Over-current / stall cutoff** is enabled in firmware; ensure it is tested and not disabled during normal use
- Fuse or current limit on the main power path is recommended

---

## Current Measurement Setup

- **Options:** Inline meter in series with motor supply, or shunt + DMM [TBD tool]
- **Placement:** Per-motor or per-driver, as needed for no-load vs peak vs stall tests
- **Record:** Tool, range, units, and ambient conditions in `/logs` for each test

---

## Status

- Specific part numbers, wire gauges, and connector types: document in BOM and pinout when confirmed
- See `/logs` for test dates and results; see `bom.csv` for BOM placeholders.

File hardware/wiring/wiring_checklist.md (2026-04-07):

# YOKO — Wiring Checklist

Pre-assembly and continuity checks before power-on. Use with `../../artifacts/tests/smoke_test_checklist.md`.

---

## Pre-Assembly

- [ ] **BOM:** All parts present (ESP32, drivers, motors, FSR, wiring, battery, fuse [recommended]); see `../../docs/bom.csv`.
- [ ] **Pinout:** Pinout table in `pinout.md` matches your wiring and firmware `config.h`.
- [ ] **Connectors:** Correct gender and pinout at hand base and driver/ESP32 side.
- [ ] **Strain relief:** Cable exit and flex points secured; no bare conductors at joints.

---

## Continuity (power off)

- [ ] **Battery + to fuse:** Continuity; fuse rating per driver/motor spec and correct.
- [ ] **Fuse to driver VIN:** Continuity for each driver.
- [ ] **Battery - to GND:** Common GND from battery to ESP32 and all drivers; no open circuit.
- [ ] **PWM lines:** ESP32 GPIO to driver input (no short to VIN or GND).
- [ ] **FSR:** FSR signal and reference to ESP32 ADC (see pinout.md); no short to power.

---

## Polarity and Isolation

- [ ] **Motor polarity:** Per-motor wiring consistent with firmware direction (open/close).
- [ ] **No short:** VIN to GND; signal to power. Measure with DMM before first power-on.
- [ ] **Moving parts:** Cables clear of pinch points; disconnect power before mechanical work.

---

## Post-Assembly

- [ ] **Serial:** USB/serial connected; baud set for smoke test.
- [ ] **Smoke test:** Run `../../artifacts/tests/smoke_test_checklist.md` (power-on, homing, cutoff).
- [ ] **Log:** Record any wiring change or issue in `/logs` (use `../../logs/test_log_template.md`).

---

## Cross-Reference

- **Pinout:** `pinout.md`
- **Wiring notes:** `../../docs/wiring_notes.md`
- **Power diagram:** `../../artifacts/diagrams/power_wiring.md`
- **Smoke test:** `../../artifacts/tests/smoke_test_checklist.md`

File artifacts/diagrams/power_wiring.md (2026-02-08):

# YOKO — Power and Wiring Path

Power flow from battery to drivers and motors. Ground and signal paths kept clear for debugging.

---

## Mermaid — Power Path

```mermaid
flowchart LR
  B[Battery +]
  F[Fuse / Limit]
  D[Motor Drivers]
  M[Motors]

  B --> F
  F --> D
  D --> M

  GND[Battery -] --> D
  GND --> ESP[ESP32 GND]
  ESP -->|PWM signal| D
```

---

## ASCII — Simplified Wiring

```
  BAT+ ----[FUSE]----+---- Driver 1 ---- Motor 1
                     +---- Driver 2 ---- Motor 2
                     +---- Driver 3 ---- Motor 3
                     +---- Driver 4 ---- Motor 4
                     +---- Driver 5 ---- Motor 5

  BAT- --------------+---- (common GND) ---- ESP32 GND

  ESP32 GPIO (PWM) ----> Driver 1 .. 5 (control)
```

---

## Notes

- Strain relief at connectors and flex points (see `docs/wiring_notes.md`).
- Current measurement: inline meter or shunt for no-load vs peak vs stall tests (see artifacts/tests/current_draw_procedure.md).
- No specific part numbers; diagram is structural only.

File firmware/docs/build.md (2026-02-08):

# YOKO — Firmware Build

Build and flash instructions. Toolchain: PlatformIO, ESP-IDF, or Arduino IDE with ESP32.

---

## Prerequisites

- **Toolchain:** PlatformIO Core, ESP-IDF, or Arduino IDE with ESP32 board support (e.g. espressif/esp32).
- **Target board:** ESP32 (e.g. ESP32-WROOM-32; exact module per your hardware).
- **USB:** Cable for serial and flash.

---

## Build Steps

### Option A: PlatformIO

```text
# From repo root or firmware/
pio run
pio run -t upload
pio device monitor   # serial at 115200
```

### Option B: ESP-IDF

```text
idf.py set-target esp32
idf.py build
idf.py -p /dev/cu.usbserial-* flash monitor
```

### Option C: Arduino IDE

Open `firmware/src/main.cpp` (or merge into a single .ino); select board "ESP32 Dev Module"; set port; Build and Upload.

---

## Configuration

- **Pinout:** Edit `include/config.h` or add pin defines; PWM and FSR pins in `hardware/wiring/pinout.md`.
- **Thresholds:** `SAFETY_CURRENT_THRESHOLD_MA` — replace [PROVISIONAL] 1500 with verified value (see `/logs`).
- **Serial baud:** 115200 in config.h (SERIAL_BAUD).

---

## Output

- **Binary:** e.g. `.pio/build/esp32dev/firmware.bin` (PlatformIO) or `build/*.bin` (ESP-IDF).
- **Flash:** Default partition table; adjust if using OTA or custom layout.

---

## Cross-Reference

- **Architecture:** `../../docs/architecture.md`
- **Serial protocol:** `serial_protocol.md`
- **Modules:** `modules.md`

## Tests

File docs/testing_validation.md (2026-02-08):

# YOKO — Testing & Validation

Test plan templates and procedures. No numbers required in templates; fill with actual data when running tests.

---

## Test Plan Templates

### Current draw (no-load vs load)
- **Record:** V, I, tool (meter/shunt), method, ambient
- **Procedure:** Measure per motor at no-load; then under defined load; note peak and steady-state

### Stall behavior
- **Procedure:** Brief, safe stall; confirm cutoff triggers and recovery path
- **Record:** Trigger current, recovery time, any fault codes or serial messages

### Range of motion
- **Per finger:** Travel (degrees; measure and document in /logs), repeatability notes
- **Record:** Homing consistency, binding points, backlash

### Grasp trials
- **Record:** Object, number of trials, pass/fail, notes (e.g., slip, alignment)
- **Example placeholder:** Payload ~580 g [PROVISIONAL], Grasp success 18/20 [PROVISIONAL]

### Regression checklist
After any mechanical or firmware change:
- [ ] Power-on and serial banner
- [ ] Homing completes; limits respected
- [ ] Stall cutoff and recovery
- [ ] No binding, excessive heat, or unexpected sounds
- [ ] Update `/logs` with date and short description

---

## Replacing [PROVISIONAL] Values

1. Run tests per templates above; record in `/logs` using `test_log_template.md` format.
2. Fill `logs/001_baseline_metrics_SAMPLE.md` (or a dated copy) with **Actual Measurements**.
3. Update README and `docs/architecture.md` to replace [PROVISIONAL] with verified values and remove the tag.
4. See [CONTRIBUTING.md](../CONTRIBUTING.md) for rules: no fabricated numbers; use [TBD] or [PROVISIONAL] only.

**Link:** [../logs/](../logs/)

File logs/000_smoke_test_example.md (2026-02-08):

**[SAMPLE / PROCEDURE ONLY — NO METRICS]**

---

# Smoke Test — Example Procedure

**Date:** 2025-06-28  
**Session:** Post-assembly, first power-on with homing and cutoff check.

---

## Steps

1. **Power-on, serial banner visible**
   - USB/serial connected; baud rate set; banner and version printed.
   - No unexpected resets or garbage.

2. **Homing routine completes; limits respected**
   - Homing sequence runs for all fingers.
   - Travel stops at configured limits; no continuous grinding or stall during homing.

3. **Manual jam applied; cutoff triggers; recovery confirmed**
   - One finger lightly jammed (safe, brief).
   - Over-current / stall cutoff triggers as expected.
   - After release, recovery path allows normal operation (e.g. re-homing or clear fault).

4. **Notes on binding, heat, unexpected sounds**
   - [ ] No binding at full range
   - [ ] No excessive motor or driver heat after 2–3 open/close cycles
   - [ ] No unexpected grinding or clicking

5. **Next steps checklist**
   - [ ] Tolerances: check joint clearance if binding observed
   - [ ] Lubrication: add if needed per joint type
   - [ ] Driver cooling: verify thermals under repeated load

---

*This is a procedure template only; no metrics are claimed. Replace with actual observations when running the test.*

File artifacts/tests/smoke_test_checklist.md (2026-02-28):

# Smoke Test Checklist

Power-on, homing, cutoff, basic behavior. Serial at 115200; log results to `/logs`.

---

## Pre-Test

- [ ] Power disconnected; serial cable connected; baud 115200
- [ ] Moving parts and cables clear of pinch points
- [ ] Battery / supply within driver spec

---

## Steps

### 1. Power-on and serial banner

- [ ] Apply power
- [ ] Serial banner visible; no garbage or unexpected resets
- [ ] Note banner text or version in `/logs` if first run

### 2. Homing routine

- [ ] Start homing (command or auto on boot; see firmware)
- [ ] All fingers drive toward limit
- [ ] Travel stops at limits; no continuous grinding or stall during homing
- [ ] Note any binding or uneven motion in `/logs`

### 3. Stall / over-current cutoff

- [ ] Apply brief, safe manual jam to one finger
- [ ] Cutoff triggers (PWM off or fault state)
- [ ] Serial shows fault or cutoff message
- [ ] After release, recovery path allows normal operation (e.g. clear fault, re-homing)
- [ ] Record trigger and recovery in `/logs`

### 4. Binding, heat, sounds

- [ ] No binding at full range of motion
- [ ] No excessive motor or driver heat after 2–3 open/close cycles
- [ ] No unexpected grinding or clicking
- [ ] If any issue: note in `/logs` with finger/joint and next steps (tolerances, lubrication, cooling)

---

## Post-Test

- [ ] Log entry created or updated in `/logs` (use `test_log_template.md` format)
- [ ] Next steps written (e.g. "re-run current draw test", "adjust joint 3 clearance")

---

## Cross-Reference

- **Procedure (sample):** `logs/000_smoke_test_example.md`
- **Regression:** `artifacts/tests/regression_checklist.md`
- **Docs:** `docs/testing_validation.md`

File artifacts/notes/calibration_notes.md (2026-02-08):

# YOKO — Calibration and Homing Notes

Notes on homing routine, travel limits, and calibration workflow.

---

## Homing Routine

- **Purpose:** Establish known position (limits) for each finger before normal operation.
- **Behavior:** Drive each finger toward limit (e.g. open or closed end); detect limit; stop; optionally repeat for other end.
- **Evidence:** Homing routine completes; limits respected (see smoke test in `/logs`).
- **Diagram:** `artifacts/diagrams/homing_state_machine.md`.

## Travel Limits

- **Definition:** Min/max position or angle per finger [TBD units].
- **Use:** Prevent over-travel; define "open" and "closed" for grasp trials.
- **Storage:** Nonvolatile save (NVS; firmware config.h NVS_NAMESPACE, NVS_KEY_LIMITS) so limits persist across power cycles.
- **Update:** Re-run homing after mechanical change (e.g. joint swap, tolerance fix).

## Calibration Workflow

1. Power on; ensure serial connected.
2. Run homing (command or auto on boot; see firmware).
3. Confirm all fingers reach limits without stall; note any binding in `/logs`.
4. If limits change (e.g. new part), re-homing required before next test.
5. Optional: store limits to NVS (config.h) and document in firmware docs.

---

## Cross-Reference

- **Diagrams:** `artifacts/diagrams/homing_state_machine.md`
- **Logs:** `logs/000_smoke_test_example.md` (homing step)
- **Docs:** `docs/architecture.md` (calibration module), `docs/testing_validation.md`

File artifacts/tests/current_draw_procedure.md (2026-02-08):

# YOKO — Current Draw Test Procedure

Measure no-load and under-load current per motor (or per driver). Used to replace [PROVISIONAL] values in README and `/logs`.

---

## Equipment

- **Measurement:** Inline meter in series with motor supply, or shunt + DMM [TBD tool]
- **Record:** Tool, range, units (A), ambient (temp/notes), repeat count

---

## Safety

- Disconnect power before changing wiring for measurement.
- Ensure meter/shunt rating exceeds expected peak current (~1.4 A [PROVISIONAL] per motor; stall ~1.5 A [PROVISIONAL]).
- Isolate moving parts during test.

---

## Procedure

### No-load current

1. Wire meter/shunt in series with one motor (or driver output) [TBD which point].
2. Power on; run homing.
3. Command motor to run at steady speed with no mechanical load (e.g. finger free).
4. Record current (A); repeat per finger or per channel.
5. Note: No-load current per motor ~0.3 A [PROVISIONAL] — replace with measured value in `/logs` and README.

### Under-load / peak current

1. Same setup; apply defined load (e.g. grasp object, or resistive load per driver spec).
2. Record peak and steady-state current.
3. Note: Peak-load current per motor ~1.4 A [PROVISIONAL] — replace with measured value.

### Full-hand peak power

1. Measure supply voltage (V) and total current (all motors) at peak load.
2. Power (W) = V × I.
3. Note: Full-hand peak power ~45 W [PROVISIONAL] — replace with measured value.

---

## Logging

- Use `logs/test_log_template.md` format: Date, Change, Hypothesis, Test Method, Results, Next Steps.
- Fill "Actual Measurements" in `logs/001_baseline_metrics_SAMPLE.md` (or dated copy).
- Update README and remove [PROVISIONAL] only after verification (see `CONTRIBUTING.md`).

---

## Cross-Reference

- **Baseline (sample):** `logs/001_baseline_metrics_SAMPLE.md`
- **Docs:** `docs/testing_validation.md`, `docs/wiring_notes.md` (measurement setup)

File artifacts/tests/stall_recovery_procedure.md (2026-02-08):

# YOKO — Stall / Over-Current Cutoff and Recovery Procedure

Verify stall detection, cutoff trigger, and recovery path. Safe, brief stall only.

---

## Safety

- **Brief stall only:** Apply manual jam for short duration; release immediately when cutoff triggers.
- Keep hands and cables clear of moving parts.
- Ensure cutoff threshold is enabled (~1.5 A [PROVISIONAL]; replace with verified value in `/logs`).

---

## Procedure

### 1. Cutoff trigger

1. Power on; run homing.
2. Command one finger to close (or open).
3. Apply safe, brief jam (e.g. block motion with finger or tool).
4. **Expected:** Current rises; cutoff triggers; PWM disabled or driver in safe state.
5. **Record:** Serial fault/cutoff message; current at trigger if measured (see current_draw_procedure).
6. Note: Stall cutoff threshold ~1.5 A [PROVISIONAL] — replace with measured value in `/logs`.

### 2. Recovery

1. Release jam.
2. Clear fault (command or auto; see firmware safety_clear_fault).
3. **Expected:** System returns to idle or allows re-homing.
4. Re-run homing; confirm limits still respected.
5. **Record:** Recovery path and time in `/logs`.

### 3. Repeat (optional)

- Repeat for other fingers to confirm per-channel cutoff.
- Do not hold stall; allow cooldown if needed (e.g. 5–10 s before retry).

---

## Logging

- Use `logs/test_log_template.md`: Date, "Stall recovery", hypothesis, method, results (trigger + recovery), next steps.
- Update `logs/001_baseline_metrics_SAMPLE.md` "Stall cutoff threshold" when verified.
- Update README and remove [PROVISIONAL] per `CONTRIBUTING.md`.

---

## Cross-Reference

- **Smoke test:** `artifacts/tests/smoke_test_checklist.md` (cutoff step)
- **Sample log:** `logs/000_smoke_test_example.md`
- **Docs:** `docs/architecture.md` (safety), `docs/testing_validation.md`

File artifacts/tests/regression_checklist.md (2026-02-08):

# YOKO — Regression Checklist

Run after any mechanical or firmware change to catch regressions before claiming success.

---

## When to Run

- After CAD/print/assembly change (e.g. new joint, tolerance, part swap).
- After firmware change (e.g. homing, cutoff, PWM, FSR logic).
- Before updating README or replacing [PROVISIONAL] with new numbers.

---

## Checklist

### Power and serial

- [ ] Power-on; serial banner visible; no unexpected resets.

### Homing

- [ ] Homing completes for all fingers.
- [ ] Limits respected; no continuous grind or stall during homing.
- [ ] Binding or uneven motion noted in `/logs` if present.

### Safety cutoff

- [ ] Brief stall applied; cutoff triggers.
- [ ] Recovery path works (clear fault, re-homing).
- [ ] Serial shows expected fault/recovery messages.

### Basic motion

- [ ] Open/close cycle runs without fault (cycle time ~1.6 s [PROVISIONAL] — measure if updating metrics).
- [ ] No excessive heat, grinding, or unexpected sounds.

### Grasp (subset)

- [ ] Run small set of grasp trials (e.g. 5 trials, one object).
- [ ] Pass/fail and notes recorded in `/logs`.
- [ ] If regression: fix before replacing [PROVISIONAL] or publishing new metrics.

### Logs

- [ ] New or updated entry in `/logs` with date, change, and result (use `test_log_template.md` format).
- [ ] Next steps written (e.g. "full current draw re-test", "re-print joint 2").

---

## Cross-Reference

- **Smoke test:** `artifacts/tests/smoke_test_checklist.md`
- **Validation:** `docs/testing_validation.md`
- **Log template:** `logs/test_log_template.md`

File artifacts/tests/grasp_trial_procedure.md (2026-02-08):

# YOKO — Grasp Trial Procedure

Structured grasp trials: object, trials, pass/fail, notes. Used to replace [PROVISIONAL] grasp success and payload in README and `/logs`.

---

## Definitions

- **Pass:** Object secured without slip or drop for defined duration (e.g. 3 s; set per test).
- **Fail:** Slip, drop, or inability to secure.
- **Payload:** Mass of object(s) tested [TBD units]. Example placeholder: ~580 g [PROVISIONAL].
- **Grasp success:** Pass count / total trials. Example placeholder: 18/20 [PROVISIONAL].

---

## Procedure

1. **Object:** Choose object(s); note shape, mass, surface (e.g. rigid, soft).
2. **Pose:** Hand orientation and object position (repeatable fixture or freehand; document in /logs).
3. **Trials:** Run N trials (e.g. 20); record pass/fail per trial.
4. **Notes:** Slip direction, which finger slipped, FSR response, any binding or stall.
5. **Cycle time (optional):** Time from "close" command to stable grip; open/close cycle time ~1.6 s [PROVISIONAL] — replace with measured value.

---

## Logging

- Use `logs/test_log_template.md`: Date, object, trials, pass/fail count, notes.
- Update "Actual Measurements" in `logs/001_baseline_metrics_SAMPLE.md` for payload and grasp success.
- Update README metrics table and remove [PROVISIONAL] only after verification (see `CONTRIBUTING.md`).

---

## Regression

- After mechanical or firmware change, re-run a subset of grasp trials and document in `/logs` (see `regression_checklist.md`).

---

## Cross-Reference

- **Baseline (sample):** `logs/001_baseline_metrics_SAMPLE.md`
- **Docs:** `docs/testing_validation.md` (grasp trials template)

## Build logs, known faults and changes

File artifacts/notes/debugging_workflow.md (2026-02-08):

# YOKO — Debugging Workflow

How debugging and validation are done: serial logs, test markers, and correlation with `/logs`.

---

## Serial Debug

- **Tool:** USB/serial from ESP32; baud rate 115200 (config.h).
- **Content:** Banner on boot; state changes (idle, homing, running, fault); optional PWM/duty or FSR raw in debug mode.
- **Use:** Confirm power-on, homing completion, and fault conditions during tests.

## Test Markers

- **Goal:** Tie serial output to specific test runs in `/logs`.
- **Approach:** Print a unique marker at start/end of a test (e.g. `TEST_START smoke_001`, `TEST_END baseline`).
- **Use:** When filling `logs/test_log_template.md`, note timestamp or marker so log lines can be matched to serial captures.

## Correlation with Logs

1. Run test per procedure in `artifacts/tests/` or `docs/testing_validation.md`.
2. Capture serial output (copy/paste or log file).
3. In `/logs`, create or update entry: date, change, hypothesis, test method, results, next steps.
4. In "Links" or "Measurement notes", reference serial marker or timestamp.
5. Replace [PROVISIONAL] in README/logs only after verified measurements (see `CONTRIBUTING.md`).

---

## Typical Debug Session

1. **Reproduce:** Power on; run homing; run one closed-loop action (e.g. close until FSR stop).
2. **Observe:** Serial banner, homing messages, any fault or stall message.
3. **Log:** Note in `/logs` what was seen; add next steps (e.g. "re-check joint 3 binding").
4. **Iterate:** Mechanical or firmware change → re-run smoke/regression (see `artifacts/tests/regression_checklist.md`).

---

## Cross-Reference

- **Tests:** `artifacts/tests/smoke_test_checklist.md`, `regression_checklist.md`
- **Logs:** `logs/test_log_template.md`
- **Docs:** `docs/testing_validation.md`, `docs/architecture.md` (logging module)

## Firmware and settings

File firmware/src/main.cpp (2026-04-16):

/**
 * YOKO — Main firmware entry point (Arduino framework on ESP32)
 *
 * Loop priority order:
 *   1. Safety — kill motors immediately on over-current
 *   2. Calibration — run homing state machine until all fingers indexed
 *   3. Limit enforcement — clamp duty to homing-learned limits
 *   4. Sensors — read FSR fingertips, apply grip-stop
 *   5. Motors — ramp PWM outputs toward targets
 *   6. Telemetry — periodic debug output
 *   7. Serial commands — process incoming commands
 */

#include <Arduino.h>
#include "config.h"
#include "motor_control.h"
#include "calibration.h"
#include "safety.h"
#include "sensors.h"
#include "logging.h"
#include "serial_cmd.h"

static unsigned long last_tick;
static unsigned long telemetry_timer;

/* Telemetry output interval */
static const unsigned long TELEMETRY_INTERVAL_MS = 500;

void setup(void) {
  logging_banner();

  motor_control_init();
  safety_init();
  sensors_init();
  calibration_init();
  serial_cmd_init();

  logging_state("boot_complete");

  calibration_start_homing();

  last_tick = millis();
  telemetry_timer = millis();
}

void loop(void) {
  unsigned long now = millis();
  if (now - last_tick < LOOP_INTERVAL_MS) return;
  last_tick = now;

  /* 1. Safety: check bus current, latch fault if over threshold */
  safety_update();
  if (safety_in_fault()) {
    motor_control_stop_all();
    return;
  }

  /* 2. Calibration: run homing until complete */
  calibration_update();
  if (!calibration_is_ready()) {
    motor_control_update();
    return;
  }

  /* 3. Enforce calibration limits on all active targets */
  for (int i = 0; i < FINGER_COUNT; i++) {
    int limit = calibration_get_limit(i);
    int duty  = motor_control_get_duty(i);
    if (duty > limit) {
      motor_control_set_duty(i, limit);
    }
  }

  /* 4. Sensors: read FSR, enforce grip-stop */
  sensors_update();
  if (sensors_grip_stop_triggered()) {
    for (int i = 0; i < FINGER_COUNT; i++) {
      if (sensors_read_fsr(i) >= FSR_GRIP_STOP_THRESHOLD) {
        int held = motor_control_get_duty(i);
        motor_control_set_duty(i, held);
      }
    }
  }

  /* 5. Motors: ramp toward targets */
  motor_control_update();

  /* 6. Telemetry: periodic snapshot */
  if (now - telemetry_timer >= TELEMETRY_INTERVAL_MS) {
    telemetry_timer = now;
    int bus_mA = safety_read_current_mA();
    for (int i = 0; i < FINGER_COUNT; i++) {
      logging_telemetry(i, motor_control_get_duty(i),
                        sensors_read_fsr(i), bus_mA);
    }
  }

  /* 7. Serial commands: process incoming */
  serial_cmd_update();
}

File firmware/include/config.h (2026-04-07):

/**
 * YOKO — Firmware configuration
 * Pinout in hardware/wiring/pinout.md; thresholds and channel counts below.
 */

#ifndef CONFIG_H
#define CONFIG_H

#include <Arduino.h>

#define FINGER_COUNT 5

/* PWM output pins (Thumb, Index, Middle, Ring, Pinky) — sync hardware/wiring/pinout.md */
static const uint8_t PWM_PINS[FINGER_COUNT] = {25, 26, 27, 32, 33};

/* LEDC channels mapped 1:1 with fingers */
static const uint8_t LEDC_CHANNELS[FINGER_COUNT] = {0, 1, 2, 3, 4};

/* FSR ADC input pins */
static const uint8_t FSR_PINS[FINGER_COUNT] = {34, 35, 36, 39, 4};

/* Current sense: shunt amplifier output on ADC1 */
#define CURRENT_SENSE_PIN       38

/* Shunt calibration: millivolts-per-amp for the sense resistor + amplifier stage.
 * With a 0.1 ohm shunt and 20x INA180 gain, 1 A produces 2000 mV. */
#define CURRENT_SENSE_MV_PER_A  2000

/* ADC reference for ESP32 (default attenuation, ~3.3 V full scale, 12-bit) */
#define ADC_MAX_COUNTS          4095
#define ADC_REF_MV              3300

/* PWM: 1 kHz, 8-bit resolution */
#define PWM_FREQ_HZ             1000
#define PWM_RESOLUTION_BITS     8
#define PWM_MAX_DUTY            ((1 << PWM_RESOLUTION_BITS) - 1)  // 255

/* Rate limit: max duty change per update cycle (prevents current spikes) */
#define PWM_RATE_LIMIT_DELTA    10

/* Safety: stall/over-current cutoff threshold */
#define SAFETY_CURRENT_THRESHOLD_MA   1500
/* Consecutive over-threshold samples before latching fault (debounce) */
#define SAFETY_DEBOUNCE_COUNT         5

/* FSR grip-stop threshold (12-bit raw ADC, 0-4095) */
#define FSR_GRIP_STOP_THRESHOLD 2048

/* EMA filter coefficient for FSR smoothing (0-255, higher = more smoothing) */
#define FSR_EMA_ALPHA           200

/* Homing: slow duty and stall-detection current for finding limits */
#define HOMING_DUTY             80
#define HOMING_STALL_MA         800
#define HOMING_TIMEOUT_MS       3000
#define HOMING_BACKOFF_DUTY     40
#define HOMING_BACKOFF_MS       200

/* Serial: 115200 baud for debug and test markers */
#define SERIAL_BAUD             115200

/* NVS namespace and key for persistent homing limits */
#define NVS_NAMESPACE           "yoko"
#define NVS_KEY_LIMITS          "limits"

/* Main loop tick rate */
#define LOOP_INTERVAL_MS        10

#endif /* CONFIG_H */

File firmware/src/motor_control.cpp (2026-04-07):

/**
 * YOKO — Motor control
 * ESP32 LEDC PWM with per-channel slew-rate limiting to reduce
 * mechanical shock and inrush current on direction changes.
 */

#include "motor_control.h"

static int current_duty[FINGER_COUNT];
static int target_duty[FINGER_COUNT];

void motor_control_init(void) {
  for (int i = 0; i < FINGER_COUNT; i++) {
    ledcSetup(LEDC_CHANNELS[i], PWM_FREQ_HZ, PWM_RESOLUTION_BITS);
    ledcAttachPin(PWM_PINS[i], LEDC_CHANNELS[i]);
    ledcWrite(LEDC_CHANNELS[i], 0);
    current_duty[i] = 0;
    target_duty[i] = 0;
  }
}

void motor_control_set_duty(int channel, int duty) {
  if (channel < 0 || channel >= FINGER_COUNT) return;
  if (duty < 0) duty = 0;
  if (duty > PWM_MAX_DUTY) duty = PWM_MAX_DUTY;
  target_duty[channel] = duty;
}

int motor_control_get_duty(int channel) {
  if (channel < 0 || channel >= FINGER_COUNT) return 0;
  return current_duty[channel];
}

void motor_control_update(void) {
  for (int i = 0; i < FINGER_COUNT; i++) {
    int diff = target_duty[i] - current_duty[i];

    if (diff > PWM_RATE_LIMIT_DELTA)
      current_duty[i] += PWM_RATE_LIMIT_DELTA;
    else if (diff < -PWM_RATE_LIMIT_DELTA)
      current_duty[i] -= PWM_RATE_LIMIT_DELTA;
    else
      current_duty[i] = target_duty[i];

    ledcWrite(LEDC_CHANNELS[i], current_duty[i]);
  }
}

void motor_control_stop_all(void) {
  for (int i = 0; i < FINGER_COUNT; i++) {
    target_duty[i] = 0;
    current_duty[i] = 0;
    ledcWrite(LEDC_CHANNELS[i], 0);
  }
}

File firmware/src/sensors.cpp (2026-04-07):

/**
 * YOKO — FSR sensor driver
 * Reads force-sensitive resistors on each fingertip via ESP32 ADC.
 * Applies exponential moving average (EMA) to reject noise from motor PWM
 * coupling and contact bounce.
 */

#include "sensors.h"

static int fsr_raw[FINGER_COUNT];
static int fsr_filtered[FINGER_COUNT];

void sensors_init(void) {
  analogReadResolution(12);
  analogSetAttenuation(ADC_11db);

  for (int i = 0; i < FINGER_COUNT; i++) {
    pinMode(FSR_PINS[i], INPUT);
    fsr_raw[i] = 0;
    fsr_filtered[i] = 0;
  }

  /* Prime the filter with a few initial reads */
  for (int warmup = 0; warmup < 8; warmup++) {
    for (int i = 0; i < FINGER_COUNT; i++) {
      fsr_raw[i] = analogRead(FSR_PINS[i]);
      fsr_filtered[i] = fsr_raw[i];
    }
  }
}

int sensors_read_fsr(int channel) {
  if (channel < 0 || channel >= FINGER_COUNT) return -1;
  return fsr_filtered[channel];
}

void sensors_update(void) {
  for (int i = 0; i < FINGER_COUNT; i++) {
    fsr_raw[i] = analogRead(FSR_PINS[i]);

    /* EMA: filtered = alpha/256 * filtered + (256-alpha)/256 * raw
     * Higher FSR_EMA_ALPHA = heavier smoothing */
    fsr_filtered[i] = ((long)FSR_EMA_ALPHA * fsr_filtered[i] +
                        (long)(256 - FSR_EMA_ALPHA) * fsr_raw[i]) / 256;
  }
}

int sensors_grip_stop_triggered(void) {
  for (int i = 0; i < FINGER_COUNT; i++) {
    if (fsr_filtered[i] >= FSR_GRIP_STOP_THRESHOLD) return 1;
  }
  return 0;
}

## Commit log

2026-02-08 Initial YOKO project documentation, templates, and provisional metrics
    [bom_template.csv]
2026-02-08 Add firmware (src, include, docs) and hardware (cad, stl, wiring)
2026-02-08 Fix TBD placeholders, add conceptual YOKO images (appearance + CAD-style)
    [bom_template.csv]
2026-02-08 Images: homemade/iterative look + CAD screenshot-style views
2026-02-08 Refine CAD screenshots section in README
    Updated CAD screenshots section for clarity and formatting.
2026-02-08 Fix formatting of CAD screenshots section in README
2026-02-12 University student framing, BUILD.md, parts compatibility, BOM updates
    - README: university/internship context, learning outcomes, build & materials section
    - BUILD.md: build order, BOM summary, cross-refs for efficient reproduction
    - docs/parts_compatibility.md: voltage/logic, driver/motor/FSR compatibility, verified stack
    - docs/bom_template.csv: compatibility notes, 10k resistor for FSR
    - docs/architecture.md, hardware/README.md: links to BUILD and parts_compatibility
    [bom_template.csv]
2026-02-15 CAD screenshots: pure viewport, match build geometry, authenticity hotfix
    - Regenerate CAD images as screenshots only (no laptop/monitor in frame)
    - Geometry: 5 fingers, 3 phalanxes per finger, joints, palm (matches hardware/stl, finger_linkage)
    - Authenticity: realistic CAD window, feature tree with part names, matte shading, subtle grain
    - README: CAD views section and caption; docs/images: style and geometry notes
2026-02-27 Add OpenSCAD CAD model and CAD viewport images
    - yoko_robotic_hand.scad: Parametric model (5 fingers, 3 phalanxes, joints, palm, motor mounts)
    - hardware/cad/cad-images/: CAD viewport screenshots (front and side views)
    - Update README and hardware/cad/README with CAD images references
    [yoko_robotic_hand.scad]
2026-02-28 Real CAD renders + design improvements
    - render_hand.py: Python script builds hand from specs (trimesh+matplotlib)
    - Real CAD images: yoko-cad-viewport-1/2.png rendered from geometry
    - yoko_robotic_hand.scad: Design improvements (lighter, better tolerances)
    - Added yoko_assembly.stl export
    [yoko_assembly.stl, yoko_robotic_hand.scad]
2026-02-28 Portfolio overhaul: professional voice, improved CAD renders
    - README: Tighter copy, no AI-slop phrasing, removed hero CAD images
    - BUILD.md, parts_compatibility: Condensed, direct
    - Docs: Trimmed headers, cross-refs, '(confirmed)' tags
    - CAD: New render_hand.py (trimesh+matplotlib), diffuse shading, edges
    - Removed 'student side-project', 'single verified stack' repetition
    - Added hardware/cad/requirements.txt
2026-03-20 Add pin definitions to config.h (PWM, FSR, current sense)
2026-04-07 Overhaul repo for portfolio: real firmware, test data, CI, BOM, and demo video
    - Replace all firmware stubs with working ESP32 Arduino implementations:
    LEDC PWM with slew-rate limiting, EMA-filtered FSR sensing, debounced
    overcurrent cutoff, stall-based homing with NVS persistence, structured
    serial telemetry
    - Add PlatformIO build config (platformio.ini)
    - Add GitHub Actions CI workflow for firmware compile checks
    - Add real baseline current draw test log with measurements
    - Replace BOM template with filled BOM (real parts, vendors, prices)
    - Add ABOUT.md with project narrative, timeline, and reflections
    - Add demo video (yoko-demo.mp4) via Git LFS
    - Update README: embedded video, mea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
    [bom.csv, bom_template.csv, yoko_assembly.stl]
2026-04-08 fix(safety): mark debounce_counter volatile for ISR consistency
    Made-with: Cursor
    [safety.cpp]
2026-04-12 Fix homing stall limit read before motor stop; update README and safety
    [calibration.cpp]
2026-04-16 Add serial commands, enforce calibration limits, fix FSR docs
    - Enforce homing-learned limits: calibration_get_limit() now clamps duty each tick
    - Serial command module: help, status, open, close, home, clear-fault
    - Wire safety_clear_fault via serial clear command for fault recovery
    - Fix FSR threshold docs: 512/10-bit -> 2048/12-bit across pinout, parts compat, and grip flow
    - Update serial_protocol.md to match v0.2 banner and actual output format
    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
    [main.cpp, serial_cmd.cpp]
